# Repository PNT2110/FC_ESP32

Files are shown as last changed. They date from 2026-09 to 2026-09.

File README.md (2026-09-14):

# FC_ESP32 Flight Controller

An ESP32-WROOM-32 based flight controller designed for 1S brushed quadcopters.

## Features
- **MCU**: ESP32-WROOM-32 (8MB Flash)
- **IMU**: MPU-6500 (SPI interface)
- **Motor Drivers**: 4x AO3400 MOSFETs for brushed motors
- **Optical Flow**: UART interface for MTF-01P sensor (JST SH1.0 4-pin)
- **Power**: 1S LiPo input, TPS63001 Buck-Boost for 3.3V, TPS61070 Boost for 5V (USB/Optical flow)
- **USB**: USB-C connector with CH340C USB-to-UART bridge
- **Expansion**: I2C and UART1 breakout headers (2.54mm pitch)
- **Battery Monitor**: Built-in voltage divider for telemetry

## Hardware Setup & Pinout
- **Motors**: J4, J5, J6, J7 pads (AO3400 driven)
- **Optical Flow (J2)**: pin 1 GND, pin 2 +5V_FLOW, pin 3 ESP32 TX (GPIO17 → sensor RX), pin 4 ESP32 RX (GPIO16 ← sensor TX). Verify the actual sensor cable orientation.
- **I2C Expansion (J8)**: VCC, GND, SDA (GPIO4), SCL (GPIO22)
- **UART1 Expansion (J9)**: VCC, GND, TX (GPIO14), RX (GPIO32)
- **Programming**: CH340C DTR/RTS auto-download circuit; no physical Boot/Reset buttons are present in the generated BOM.

## Current status

The subsequent datasheet review found B.Cu tracks inside the ESP32 antenna region,
power-layout concerns and incomplete flight features despite clean ERC/DRC.
See `BAO_CAO_KIEM_TRA_MACH.md` and `validation/datasheet_audit/LOG_KIEM_TRA.md`.
The independent antenna check fails; do not interpret the routing checks below as
proof that the design is ready to operate or manufacture.

PCB routing and final ERC/DRC/parity checks passed on 2026-09-14 (KiCad 10.0.6):
zero violations and zero unconnected items. Motor solder pads moved 1.5 mm inward;
J2 faces outward. See `validation/FINAL_REVIEW.md` and `validation/final_3d.png`.
Not released for manufacturing or flight. Motor pitch is
66.8 mm, prop diameter 40 mm, board thickness 0.8 mm. Components are on the front;
copper routing uses both layers. Firmware motor actuation is disabled by default;
see `firmware/README.md`.

## Reproducible hardware workflow

Use system Python with KiCad 10 `pcbnew`, `sexpdata` and Shapely installed.
The generator replaces the working PCB and therefore discards its routing.
Back up a routed board before regenerating.

```sh
/usr/bin/python3 tools/build_fc.py
/usr/bin/python3 tools/prepare_route.py
# Route the new FC_ESP32/FC_ESP32.dsn with Freerouting and save FC_ESP32.ses.
/usr/bin/python3 tools/import_route.py
/usr/bin/python3 tools/finish_copper.py
python3 tools/validate_fc.py
```

`build_fc.py` now includes clearance-preserving placement and updates the BOM and
design coordinates. Session import validates placement before replacing copper.
The legacy `critical_routes.py` and `repair_connections.py` contain assumptions
from the older layout and are not part of this workflow.

On the current machine, prefix system-Python commands with
`PYTHONPATH=/home/pnt/miniconda3/lib/python3.14/site-packages`.
This path is environment-specific. Generation was verified in an isolated copy;
all 72 component placements, orientations, values, footprints and nets matched.

The current SES predates the final repairs: do not import it onto the final PCB.
`validation/final_routed.kicad_pcb` preserves the reviewed routing.
`tools/repair_c3_ground.py` documents the deterministic final copper repair from
`validation/only_c3_ground_remaining.kicad_pcb` to its candidate output.

Open `FC_ESP32/FC_ESP32.kicad_pro` for review. Validation records current ERC,
DRC, netlist parity and source hashes in `FC_ESP32/validation_summary.json` and
returns nonzero on errors. Reports do not replace current/thermal analysis or
bench testing. `gerbers/` contains stale outputs, not an approved release.

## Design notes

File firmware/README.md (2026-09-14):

# Firmware bring-up

Current firmware includes MPU-6500 acquisition, gyro calibration, attitude estimation,
PID/mixing, battery monitoring and an ESP-NOW command/arming/failsafe path.
Motor actuation is disabled by default (`CONFIG_FC_ENABLE_MOTORS`); the default
build keeps PWM outputs at zero. Host tests pass for the sensor driver, protocol,
arming/failsafe and controller fault/output limits. These tests do not establish
stable flight: transmitter integration, sensor axes, motor order, control tuning
and battery behavior still require hardware testing.

Verified build: ESP-IDF 5.4.2, ESP32 target. Uses `driver/i2c_master.h` and `esp_adc/adc_oneshot.h`:

```sh
idf.py set-target esp32
idf.py build
```

Run from this directory after sourcing the ESP-IDF `export.sh`. The current validation SDK is `/tmp/fc-esp-idf` and its tool installation is
`/tmp/fc-idf-tools` (`IDF_TOOLS_PATH`). These temporary paths do not survive cleanup.
Host SPI regression tests (from repository root):

```sh
bash firmware/tests/run.sh
```

They verify SPI byte alignment, signed conversion, sensor range configuration,
identity rejection and transfer failure handling. They do not emulate electrical
hardware or replace an ESP32 build/bench test.

Driver references:
- https://invensense.tdk.com/wp-content/uploads/2015/02/MPU-6500-Register-Map2.pdf
- https://docs.espressif.com/projects/esp-idf/en/latest/esp32/api-reference/peripherals/spi_master.html

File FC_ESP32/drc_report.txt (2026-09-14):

** Drc report for FC_ESP32.kicad_pcb **
** Created on 2026-09-13T22:51:14 **
** Report includes: Errors, Warnings **

** Found 24 DRC violations **
[silk_overlap]: Silkscreen clearance (board setup constraints silk clearance 0.1000 mm; actual 0.0039 mm)
    Rule: board setup constraints silk; warning
    @(110.5600 mm, 109.9850 mm): Segment of J2 on F.Silkscreen
    @(110.5000 mm, 110.0000 mm): PCB text '1S ONLY' on F.Silkscreen
[silk_over_copper]: Silkscreen clipped by solder mask
    Local override; warning
    @(110.5000 mm, 110.0000 mm): PCB text '1S ONLY' on F.Silkscreen
    @(109.7000 mm, 109.1750 mm): Pad MP [<no net>] of J2 on F.Cu
[silk_over_copper]: Silkscreen clipped by solder mask
    Local override; warning
    @(110.5000 mm, 114.0000 mm): PCB text 'BAT+  BAT-' on F.Silkscreen
    @(108.5000 mm, 112.2000 mm): Pad 1 [VBAT] of J3 on F.Cu
[silk_over_copper]: Silkscreen clipped by solder mask
    Local override; warning
    @(110.5000 mm, 114.0000 mm): PCB text 'BAT+  BAT-' on F.Silkscreen
    @(112.5000 mm, 112.2000 mm): Pad 2 [GND] of J3 on F.Cu
[silk_over_copper]: Silkscreen clipped by solder mask
    Local override; warning
    @(110.5000 mm, 114.0000 mm): PCB text 'BAT+  BAT-' on F.Silkscreen
    @(113.1000 mm, 114.5500 mm): Pad 2 [GND] of Q3 on F.Cu
[silk_over_copper]: Silkscreen clipped by solder mask
    Local override; warning
    @(90.0000 mm, 85.2500 mm): Circle of U1 on F.Silkscreen
    @(89.1000 mm, 85.0500 mm): Pad 2 [GND] of Q1 on F.Cu
[text_height]: Text height out of range (board setup constraints silk text height min height 0.8000 mm; actual 0.6500 mm)
    Rule: board setup constraints silk text height; warning
    @(100.0000 mm, 117.0000 mm): PCB text 'USB' on F.Silkscreen
[text_height]: Text height out of range (board setup constraints silk text height min height 0.8000 mm; actual 0.6500 mm)
    Rule: board setup constraints silk text height; warning
    @(110.5000 mm, 110.0000 mm): PCB text '1S ONLY' on F.Silkscreen
[text_height]: Text height out of range (board setup constraints silk text height min height 0.8000 mm; actual 0.6500 mm)
    Rule: board setup constraints silk text height; warning
    @(110.5000 mm, 114.0000 mm): PCB text 'BAT+  BAT-' on F.Silkscreen
[via_dangling]: Via is not connected or connected on only one layer
    Local override; warning
    @(86.5514 mm, 87.3786 mm): Via [GATE1] on F.Cu - B.Cu
[via_dangling]: Via is not connected or connected on only one layer
    Local override; warning
    @(110.3922 mm, 92.1230 mm): Via [PWM2] on F.Cu - B.Cu
[track_dangling]: Track has unconnected end
    Local override; warning
    @(99.6000 mm, 109.9000 mm): Track [SPI_MISO] on B.Cu, length 0.5160 mm
[track_dangling]: Track has unconnected end
    Local override; warning
    @(100.4000 mm, 109.9359 mm): Track [REGOUT] on F.Cu, length 0.5859 mm
[track_dangling]: Track has unconnected end
    Local override; warning
    @(101.9708 mm, 109.9000 mm): Track [IMU_INT] on B.Cu, length 0.6708 mm
[track_dangling]: Track has unconnected end
    Local override; warning
    @(100.4011 mm, 104.1989 mm): Track [IMU_CS] on F.Cu, length 0.2844 mm
[track_dangling]: Track has unconnected end
    Local override; warning
    @(100.2000 mm, 104.4000 mm): Track [IMU_CS] on B.Cu, length 0.9881 mm
[track_dangling]: Track has unconnected end
    Local override; warning
    @(98.3500 mm, 104.4000 mm): Track [SPI_MOSI] on B.Cu, length 2.5460 mm
[via_dangling]: Via is not connected or connected on only one layer
    Local override; warning
    @(95.9221 mm, 89.0085 mm): Via [+5V_FLOW] on F.Cu - B.Cu
[via_dangling]: Via is not connected or connected on only one layer
    Local override; warning
    @(112.0000 mm, 106.5347 mm): Via [+5V_FLOW] on F.Cu - B.Cu
[via_dangling]: Via is not connected or connected on only one layer
    Local override; warning
    @(111.5559 mm, 97.6595 mm): Via [EN] on F.Cu - B.Cu
[via_dangling]: Via is not connected or connected on only one layer
    Local override; warning
    @(116.8767 mm, 115.3522 mm): Via [GATE3] on F.Cu - B.Cu
[via_dangling]: Via is not connected or connected on only one layer
    Local override; warning
    @(109.3222 mm, 115.4896 mm): Via [M3_NEG] on F.Cu - B.Cu
[via_dangling]: Via is not connected or connected on only one layer
    Local override; warning
    @(95.0887 mm, 110.4342 mm): Via [VSYS] on F.Cu - B.Cu
[via_dangling]: Via is not connected or connected on only one layer
    Local override; warning
    @(104.1904 mm, 101.2292 mm): Via [PWM3] on F.Cu - B.Cu

** Found 16 unconnected pads **
[unconnected_items]: Missing connection between items
    Local override; error
    @(110.3922 mm, 92.1230 mm): Track [PWM2] on F.Cu, length 0.5748 mm
    @(91.5000 mm, 97.9400 mm): Pad 11 [PWM2] of U1 on F.Cu
[unconnected_items]: Missing connection between items
    Local override; error
    @(99.4000 mm, 108.5450 mm): Pad 8 [+3V3_IMU] of U2 on F.Cu
    @(98.8000 mm, 109.3500 mm): Track [+3V3_IMU] on B.Cu, length 1.6539 mm
[unconnected_items]: Missing connection between items
    Local override; error
    @(100.2530 mm, 108.7310 mm): Track [SPI_MISO] on B.Cu, length 2.3442 mm
    @(99.8000 mm, 108.5450 mm): Pad 9 [SPI_MISO] of U2 on F.Cu
[unconnected_items]: Missing connection between items
    Local override; error
    @(100.4000 mm, 109.9359 mm): Track [REGOUT] on F.Cu, length 0.5859 mm
    @(100.2000 mm, 108.5450 mm): Pad 10 [REGOUT] of U2 on F.Cu
[unconnected_items]: Missing connection between items
    Local override; error
    @(101.0000 mm, 108.5450 mm): Pad 12 [IMU_INT] of U2 on F.Cu
    @(101.9708 mm, 109.9000 mm): Track [IMU_INT] on B.Cu, length 0.6708 mm
[unconnected_items]: Missing connection between items
    Local override; error
    @(100.4011 mm, 104.1989 mm): Track [IMU_CS] on F.Cu, length 0.2844 mm
    @(100.2000 mm, 104.4000 mm): Track [IMU_CS] on B.Cu, length 0.9881 mm
[unconnected_items]: Missing connection between items
    Local override; error
    @(100.2000 mm, 104.4000 mm): Track [IMU_CS] on B.Cu, length 0.9881 mm
    @(99.8000 mm, 105.4550 mm): Pad 22 [IMU_CS] of U2 on F.Cu
[unconnected_items]: Missing connection between items
    Local override; error
    @(99.4000 mm, 105.4550 mm): Pad 23 [SPI_SCK] of U2 on F.Cu
    @(108.5000 mm, 95.4000 mm): Pad 30 [SPI_SCK] of U1 on F.Cu
[unconnected_items]: Missing connection between items
    Local override; error
    @(98.3500 mm, 104.4000 mm): Track [SPI_MOSI] on B.Cu, length 2.5460 mm
    @(99.0000 mm, 105.4550 mm): Pad 24 [SPI_MOSI] of U2 on F.Cu
[unconnected_items]: Missing connection between items
    Local override; error
    @(110.6000 mm, 98.0000 mm): Pad 3 [EN] of Q5 on B.Cu
    @(90.2583 mm, 91.9671 mm): Track [EN] on F.Cu, length 1.0851 mm
[unconnected_items]: Missing connection between items
    Local override; error
    @(102.7500 mm, 97.6350 mm): Pad 5 [USB_DP] of U3 on B.Cu
    @(100.1402 mm, 111.3527 mm): Track [USB_DP] on F.Cu, length 0.2183 mm
[unconnected_items]: Missing connection between items
    Local override; error
    @(108.0000 mm, 109.9100 mm): Pad 1 [PWM3] of R19 on F.Cu
    @(97.2374 mm, 101.2292 mm): Track [PWM3] on F.Cu, length 6.9530 mm
[unconnected_items]: Missing connection between items
    Local override; error
    @(87.5000 mm, 89.0000 mm): Pad 2 [BOOST_SW] of L2 on B.Cu
    @(90.8625 mm, 91.4500 mm): Pad 1 [BOOST_SW] of U6 on B.Cu
[unconnected_items]: Missing connection between items
    Local override; error
    @(97.2500 mm, 96.3650 mm): Pad 13 [DTR] of U3 on B.Cu
    @(108.4000 mm, 98.5100 mm): Track [DTR] on B.Cu, length 0.0806 mm
[unconnected_items]: Missing connection between items
    Local override; error
    @(109.4000 mm, 91.0000 mm): Pad 4 [BUCK_L1] of U5 on B.Cu
    @(112.7000 mm, 92.1000 mm): Pad 1 [BUCK_L1] of L1 on B.Cu
[unconnected_items]: Missing connection between items
    Local override; error
    @(109.4000 mm, 90.0000 mm): Pad 2 [BUCK_L2] of U5 on B.Cu
    @(112.7000 mm, 88.9000 mm): Pad 2 [BUCK_L2] of L1 on B.Cu

** Found 0 Footprint errors **

** Ignored checks **
    - Footprint has no courtyard defined
    - Track endpoint not centered on via
    - Tuning profile track geometries
    - Footprint doesn't match symbol's footprint filters
    - Footprint component type doesn't match footprint pads

** End of Report **

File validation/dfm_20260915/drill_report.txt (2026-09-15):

Drill report for FC_ESP32.kicad_pcb
Created on 2026-09-15T04:53:47

Copper Layer Stackup:
    =============================================================
    L1 :  F.Cu                      front
    L2 :  B.Cu                      back

Drill file 'FC_ESP32-PTH.drl' contains
    plated through holes:
    =============================================================
    T1  0.300mm  0.0118"  (163 holes))
    T2  0.600mm  0.0236"  (4 holes)  (with 4 slots)
    T3  1.000mm  0.0394"  (8 holes))

    Total plated holes count 175

Drill file 'FC_ESP32-NPTH.drl' contains
    unplated through holes:
    =============================================================
    T1  0.650mm  0.0256"  (2 holes))
    T2  8.600mm  0.3386"  (4 holes))

    Total unplated holes count 6

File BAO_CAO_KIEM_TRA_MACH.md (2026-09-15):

> Cập nhật 15/09/2026: đã sửa đường VBAT/PWM1 xâm lấn antenna; kiểm tra độc lập cả hai lớp không còn track/via/pad/zone trong vùng antenna. ERC/DRC và kiểm tra đồng nhất schematic/PCB sạch. Chi tiết mới nhất: [log sửa antenna](validation/antenna_fix/BAO_CAO.md). Các nhận xét antenna chưa đạt ở nội dung cũ bên dưới là kết quả trước đợt sửa này.

# Báo cáo đối chiếu datasheet, sơ đồ, PCB, 3D và firmware FC_ESP32

Ngày kiểm tra: 14/09/2026. Công cụ: KiCad 10.0.6, Python/pcbnew, kiểm tra mã C trên host với AddressSanitizer và UndefinedBehaviorSanitizer.

## 1. Kết luận cần đọc trước

**Chưa thể kết luận mạch chắc chắn chạy, và chưa nên đặt sản xuất để bay ngay.** Sơ đồ chân tín hiệu/nguồn đã kiểm tra khớp; ERC/DRC/parity vẫn sạch. Nhưng rà soát theo datasheet đã phát hiện vấn đề anten, layout nguồn và cấu hình/tính năng firmware mà các kiểm tra đó không chứng minh được.

Đặc biệt, **VBAT và PWM1 đang chạy ở B.Cu trong vùng anten ESP32**. Rule area hiện tại chỉ cấm track F.Cu; rule trên hai lớp cấm đổ đồng nhưng cho phép track. Vì vậy kết quả DRC bằng 0 là đúng với bộ rule hiện hành, nhưng không có nghĩa layout đáp ứng yêu cầu anten. Kết luận hoàn tất ở báo cáo trước chỉ có giá trị về kết nối theo rule, không phải xác nhận đủ điều kiện hoạt động.

Trong lượt này chỉ bổ sung công cụ kiểm tra, log và báo cáo; chưa sửa routing hay đổi cấu hình firmware để tránh che mất trạng thái đang được đánh giá.

## 2. Đã kiểm tra những gì, bằng chứng ở đâu

| Hạng mục | Kết quả | Bằng chứng |
|---|---|---|
| Schematic ERC | 0 vi phạm | `validation/datasheet_audit/erc_drc.log` |
| PCB DRC, refill zones | 0 vi phạm theo rule hiện tại | Cùng log; `FC_ESP32/drc_current.json` |
| Kết nối thiếu, schematic parity | Đều 0 | `FC_ESP32/validation_summary.json` |
| Đối chiếu pin độc lập | 135 pad instances được so với mapping datasheet/yêu cầu, không sai net | `validation/datasheet_audit/audit.json` |
| Toàn bộ pad | 279 pad instances ghi lại số chân, tên chân schematic, net schematic/PCB, tọa độ, góc, mặt | `validation/datasheet_audit/pin_audit.csv` |
| Pin không dùng/reserved/flash | Không thấy bị nối vào net chức năng ngoài ý muốn trong các nhóm đã kiểm tra | `tools/review_design.py` |
| GPIO firmware | Các macro giao tiếp/motor khớp yêu cầu và PCB | `validation/datasheet_audit/pin_check.log` |
| Motor pitch, pad dịch, J2, độ dày, netclass | Audit đạt | `validation/datasheet_audit/invariants.json` |
| Anten kiểm tra độc lập | **Không đạt**: 23 đoạn track giao vùng anten; tổng diện tích hợp giao khoảng 2.823 mm²; VBAT/PWM1 ở B.Cu | `validation/datasheet_audit/antenna_audit.json` |
| Firmware host tests | Cả 3 nhóm đạt | `validation/datasheet_audit/firmware_tests.log` |
| ESP-IDF build toàn bộ hiện tại | Chưa chạy trong lượt này; không tìm thấy SDK/toolchain ở các vị trí đã dùng trước | Không coi host tests là build ESP32 |
| 3D mặt trên/mặt dưới | Đã render mới và xem trực tiếp | `validation/datasheet_audit/top_3d.png`, `bottom_3d.png` |
| Đo trên PCB thật, dòng/dao động/nhiệt, bay | Chưa thực hiện | Chưa có phần cứng/kết quả đo |

SHA-256 của schematic, PCB, project, firmware và datasheet local được lưu trong `validation/datasheet_audit/audit.json`. Log kiểm tra không được hiểu là thử nghiệm vật lý.

## 3. Các điểm cần xử lý theo mức ưu tiên

| ID | Mức | Phát hiện và ảnh hưởng | Việc cần làm |
|---|---|---|---|
| RF-01 | Cao | VBAT/PWM1 chạy dưới anten trong hình chữ nhật x=91…109, y=77.75…84.05 mm. Có thể làm giảm tầm liên lạc, tăng nhiễu, mất gói ESP-NOW | Sửa rule cấm track/via/pour trên cả hai lớp tại vùng anten, đi lại hai net, chạy DRC và đo link khi motor hoạt động |
| PWR-01 | Cao | BOOST_FB dài tổng 28.272 mm, U6–C17 cách tâm 7.653 mm; feedback trở lớn 1.8 MΩ/200 kΩ dễ nhạy nhiễu. Đường switch boost dài 11.795 mm | Bố trí lại cụm U6/L2/C17/R12/R13 thành cụm ngắn, có tụ input sát U6; đo ổn định khởi động, ripple và tải bước |
| CFG-01 | Cao trước nạp | BOM ghi ESP32-WROOM-32 (8MB), `sdkconfig.defaults` ép 8 MB. Datasheet ESP32-WROOM-32 tiêu chuẩn ghi 4 MB | Xác định đúng mã module/flash thực tế, kiểm tra flash ID, đồng bộ BOM và sdkconfig. Không tự coi tên thư viện “8MB” là bằng chứng |
| PWR-02 | Cao trước chạy motor | Chưa có mã/datasheet motor 8520 cụ thể, dòng chạy/kẹt và dữ liệu lực đẩy với Gemfan 1635 ba lá. Chưa chứng minh đường nguồn/MOSFET/diode đủ tải | Đo dòng bằng nguồn giới hạn dòng, xác nhận điện áp motor, tính lại đường đồng/diode/nhiệt theo tải thật |
| BOM-01 | Cao trước đặt hàng | L2 chỉ ghi “4.7uH >=1A shielded”, footprint 4×4, chưa có mã. L1 cũng cần xác nhận mã đầy đủ, footprint và đặc tính đúng bản mua | Chốt mã linh kiện, Isat/Irms/DCR/dung sai, điện dung hiệu dụng các MLCC ở điện áp làm việc |
| ASM-01 | Cần xác minh trước lắp | U2 có pad 25 GND trong footprint/library, trong bảng chân datasheet local chỉ định nghĩa 24 chân và không quy định pad 25 là chân tín hiệu GND | Lấy hướng dẫn assembly/land pattern đúng MPU-6500 để xác nhận nối/solder exposed pad; không suy từ hình 3D QFN chung |
| FW-01 | Chưa hoàn thiện chức năng bay | Mặc định motor bị khóa; peer/key ESP-NOW trống; chưa có firmware tay phát trong repo; chưa xử lý optical flow | Hoàn thành tay phát, cấu hình peer/key/channel, parser cảm biến, kiểm tra failsafe và cơ chế điều khiển trước khi mở motor |
| FW-02 | Cao trước bay | PID là hệ số tạm, chưa chứng minh trục IMU/dấu mixer/chiều motor; lỗi IMU hoặc pin dưới 3.5 V làm dừng motor ngay | Kiểm chứng dấu phản hồi, ngưỡng pin dưới tải, hành vi lỗi; cơ chế ngắt này không phải hạ cánh an toàn |
| PCB-01 | Cần đánh giá nguồn | BUCK_L1 có 7.601 mm, BUCK_L2 có 10.296 mm đồng; có đoạn thoát 0.25 mm dù netclass MotorPower 0.8 mm. VSYS có đoạn 0.2402/0.3 mm | Rà lại từng đoạn nguồn xung theo dòng đỉnh; không coi tên netclass là chiều rộng thật của mọi đoạn |
| USB-01 | Cần thử giao tiếp/ESD | USB_DP/DM có tổng 36.581/33.442 mm track, U4 cách J1 khoảng 8.112 mm theo tâm | Xem đường hồi và nhánh ESD, tối ưu vị trí U4 gần cổng, thử nhận USB cả hai chiều cắm; đây không phải kết quả đo impedance/ESD |

TI yêu cầu đường dòng xung ngắn/rộng, tụ và cuộn cảm sát IC, feedback sát control ground. Các chiều dài trên là tổng chiều dài segment mỗi net, không phải phép đo loop inductance hay trực tiếp delay; nhận định rủi ro dựa vào cả vị trí và routing. Nguồn: datasheet TPS6300x §10.1 và TPS6107x §13.1 trong `data_sheet/`.

Về anten, [Espressif hướng dẫn đặt anten ra ngoài board hoặc tạo khoảng trống thích hợp, rồi kiểm tra tầm liên lạc trên sản phẩm hoàn chỉnh](https://docs.espressif.com/projects/esp-hardware-design-guidelines/en/latest/esp32/pcb-layout-design.html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). Lỗi RF-01 được đo trực tiếp từ đồng PCB, không suy đoán từ màu ảnh 3D.

Về flash, [datasheet chính thức ESP32-WROOM-32](https://documentation.espressif.com/esp32-wroom-32_datasheet_en.html) mô tả module tiêu chuẩn 4 MB. Có thể phần cứng mua thực tế là biến thể khác; phải xác nhận thay vì kết luận chắc chắn đã mua sai.

## 4. Sơ đồ khối và nguyên lý mạch

```mermaid
flowchart LR
  BAT["Pin 1S / J3"] --> VBAT["VBAT"]
  VBAT --> MOT["J4–J7 / motor 8520"]
  MOT --> FET["Q1–Q4 low-side PWM"]
  FET --> GND["GND"]
  VBAT --> D5["D5 SS16"]
  USB["J1 USB-C 5V"] --> D6["D6 SS16"]
  D5 --> VSYS["VSYS"]
  D6 --> VSYS
  VSYS --> U5["U5 TPS63001 / 3.3V"]
  U5 --> MCU["ESP32 / U1"]
  U5 --> CH["CH340C / U3"]
  U5 --> IMU["MPU6500 / U2 qua R5"]
  U5 --> U6["U6 TPS61070 / 5V_FLOW"]
  U6 --> FLOW["J2 / MTF-01P"]
  USB <-->|"D+/D- qua bảo vệ U4"| CH
  CH <-->|"UART0 / auto-download"| MCU
  MCU <-->|"SPI"| IMU
  MCU <-->|"UART2"| FLOW
  MCU -->|"GPIO25/26/27/33"| FET
  VBAT --> ADC["R3/R4/C4 / GPIO35"]
  ADC --> MCU
  TX["Tay phát ESP-NOW riêng"] -.-> MCU
```

### Nguồn pin, USB và 3.3 V

J3 pin 1 là VBAT, pin 2 là GND. VBAT cấp motor trực tiếp và đi qua D5 tới VSYS. USB VBUS đi qua D6 tới VSYS. D5/D6 tạo OR nguồn bằng Schottky: cathode pin 1 cùng ở VSYS, anode pin 2 ở từng nguồn vào. Khi có USB, 5 V thường chiếm ưu thế cấp logic. Đây **không phải mạch sạc pin**, không cân bằng pin, không bảo vệ đảo cực toàn bộ mạch. Motor nối trực tiếp VBAT nên D5 không bảo vệ nhánh motor khi đấu ngược pin. Không đưa nguồn 5 V vào J3.

U5 TPS63001 tạo 3.3 V từ VSYS. Pin 1 VOUT và pin 10 FB nối +3V3 đúng yêu cầu bản fixed 3.3 V; L1 nối pin 4–2. Pin 5 VIN, 6 EN, 7 PS/SYNC nối VSYS; PS/SYNC mức cao tắt power-save. Pin 8 VINA được lọc qua R11=100 Ω, C15=100 nF; pin 3 PGND, 9 GND, pad 11 về GND. C12/C13 là tụ đầu vào/ra. Dải input khuyến nghị của IC là 1.8–5.5 V, nhưng cần trừ sụt áp D5 và kiểm tra tải bước/độ bão hòa cuộn cảm. Datasheet TPS6300x, bảng Pin Functions và phần thiết kế ứng dụng.

### Nguồn 5 V cảm biến

U6 TPS61070 lấy đầu vào từ **+3V3**, không trực tiếp từ pin 1S. Pin 6 VBAT và pin 3 EN cùng +3V3; L2 từ +3V3 đến pin 1 SW; pin 2 GND; pin 5 VOUT là +5V_FLOW. R12 từ VOUT đến FB, R13 từ FB xuống GND:

`Vout ≈ 0.5 × (1 + 1.8M / 200k) = 5.0 V`.

Nếu chỉ xét 1% điện trở và VFB=0.495…0.505 V từ datasheet, khoảng tĩnh cực trị xấp xỉ 4.862…5.142 V; không bao gồm ripple, tải bước hay layout. C17 lọc đầu ra; C18 nằm ở nhánh cảm biến.

[MTF-01P dùng 5 V, dòng trung bình 100 mA, UART LVTTL 3.3 V/115200](https://micoair.cn/zh/docs/sensors/sensors/mtf-01p-sensors). Về mức logic có thể nối UART trực tiếp với ESP32. Tải cảm biến 0.5 W, giả thiết boost hiệu suất 85% thì lấy khoảng 178 mA từ rail 3.3 V, chưa cộng ESP32/CH340/IMU và dòng đỉnh. TPS61070 có giới hạn dòng switch, không được diễn giải là “cấp 600 mA ở 5 V”. Chưa có bằng chứng đủ tải đồng thời khi Wi-Fi phát và motor gây nhiễu.

Đường +5V_FLOW có 8.448 mm rộng 0.18 mm, còn lại 0.4 mm. Phép tính đồng 35 µm trong `validation/flow_power_review.json` cho tổng điện trở segment khoảng 0.114 Ω và sụt khoảng 11.4 mV ở 100 mA. Đây chỉ là đánh giá tổn hao DC của đường đồng, không giải quyết rủi ro layout boost nêu trên.

### MCU, reset, nạp chương trình

ESP32 pin 2 dùng 3.3 V; pin 1/15/38 và exposed ground pad 39 về GND. R1=10 kΩ kéo EN lên, C3=1 µF về GND tạo hằng số RC danh định 10 ms. R2=10 kΩ kéo GPIO0/BOOT lên. GPIO6–11 dùng cho flash được để không nối ra ứng dụng; GPIO34/35 là input-only, đang dùng đúng cho INT và ADC.

CH340C được cấp 3.3 V ở VCC pin 16 và V3 pin 4, đúng chế độ 3.3 V trong datasheet; C9=100 nF decouple. TXD pin 2 tới RX0 ESP32; RXD pin 3 nhận TX0 ESP32. CH340C có oscillator nội, không cần thạch anh ngoài. Pin 15 R232 nối GND; pin 7 NC và các modem input không dùng được để trống.

Q5/Q6 MMBT3904 có pin 1 base, 2 emitter, 3 collector. Q5 kéo EN khi DTR cao/RTS thấp; Q6 kéo BOOT khi RTS cao/DTR thấp. Hai mức DTR/RTS bằng nhau không bật transistor. Tên DTR#/RTS# active-low ở driver cần phân biệt với mức điện áp trên chân. Mạch này cho phép auto-download nhưng vẫn phải thử bằng esptool/driver thật. Không có nút BOOT/RESET vật lý trong BOM hiện tại.

USB-C có CC1/CC2 mỗi đường điện trở 5.1 kΩ về GND; D+ A6/B6 nối nhau, D− A7/B7 nối nhau. U4 USBLC6-2SC6 nối 1/6 với D−, 3/4 với D+, 2 GND và 5 VBUS, khớp [sơ đồ chân ST](https://www.st.com/resource/en/datasheet/usblc6-2.pdf). SBU không dùng. USB cung cấp giao tiếp USB–UART, không phải USB native của MCU, cũng không phải bộ sạc LiPo.

### MPU-6500

R5=10 Ω và các tụ C5/C6/C8 lọc rail +3V3_IMU. Pin 8 VDDIO và 13 VDD dùng rail này; pin 18 GND. Pin 10 REGOUT chỉ nối C7=100 nF về GND, không dùng làm nguồn ngoài. FSYNC pin 11 và reserved pin 20 nối GND; pin 19 reserved để trống. CS pin 22 được R6 kéo lên; SCLK pin 23, SDI pin 24, SDO pin 9, INT pin 12. Các chân NC và AUX không dùng không bị nối ra mạch chức năng. Đối chiếu datasheet MPU-6500 bảng 10, trang 17 và bảng linh kiện ứng dụng trang 19.

**Riêng exposed pad 25:** thư viện thêm pad này và nối GND; pin table local không đủ chứng cứ về yêu cầu hàn/nối pad đáy. Vấn đề này còn mở, không được tính là đã đạt hoàn toàn theo datasheet.

### Motor và phép đo pin

Mỗi motor nhận cực + từ VBAT, cực − đi vào drain pin 3 AO3400. Source pin 2 về GND; gate pin 1 nhận PWM qua 100 Ω, có 100 kΩ kéo xuống để tắt khi MCU chưa điều khiển. D1–D4 SS16 có cathode về VBAT, anode về drain: hướng diode hồi tiếp đúng. Tụ 100 nF trên mỗi nhánh giúp lọc nhiễu; hiệu quả còn phụ thuộc chiều dài dây và nguồn nhiễu tại chổi than.

AO3400 có RDS(on) tối đa 52 mΩ được đặc tả ở VGS=2.5 V, nên có cơ sở dùng gate logic 3.3 V. Không được lấy con số dòng 5.8 A ở VGS=10 V làm mức chịu tải đảm bảo trên cánh PCB nhỏ. SS16 được định mức dòng trung bình 1 A theo điều kiện datasheet; cần tính dòng hồi tiếp theo dạng sóng PWM, không chỉ dòng trung bình nguồn. Ví dụ tổn hao dẫn MOSFET xấp xỉ `I² × RDS(on) × duty`; ở 2 A, 52 mΩ và duty 1 đã là 0.208 W trước khi tính tăng điện trở theo nhiệt. Đây là ví dụ tính, không phải dòng motor đã đo.

R3/R4=100 kΩ chia VBAT đôi vào GPIO35/ADC1_CH7. Ở pin 4.35 V, ADC khoảng 2.175 V; dòng cầu chia khoảng 21.75 µA. C4=100 nF và trở Thevenin 50 kΩ tạo hằng số thời gian khoảng 5 ms. Firmware đổi ADC đã hiệu chuẩn ra volt rồi nhân 2. Sai số điện trở/ADC/Vref phải so lại bằng đồng hồ. Nhãn pin 3.8 V là điện áp danh định; điện áp sạc tối đa phải lấy từ chính nhãn/datasheet pack, không tự suy chắc chắn là 4.35 V.

## 5. Bảng chân ESP32 và nối thiết bị ngoài

Quy ước nhìn **mặt linh kiện**, anten ở trên, USB ở dưới. GPIO là số GPIO của ESP32; “pad U1” là số chân module, hai loại số không thay thế nhau.

| Chức năng | GPIO | Pad U1 | Đầu bên kia |
|---|---:|---:|---|
| Motor M1 — trên trái | 25 | 10 | R15 → Q1 gate → J4 |
| Motor M2 — trên phải | 26 | 11 | R17 → Q2 gate → J5 |
| Motor M3 — dưới phải | 27 | 12 | R19 → Q3 gate → J6 |
| Motor M4 — dưới trái | 33 | 9 | R21 → Q4 gate → J7 |
| MPU MISO | 19 | 31 | U2 pin 9 SDO |
| MPU MOSI | 23 | 37 | U2 pin 24 SDI |
| MPU SCLK | 18 | 30 | U2 pin 23 |
| MPU CS | 21 | 33 | U2 pin 22 |
| MPU INT | 34 | 6 | U2 pin 12 |
| Optical-flow TX | 17 | 28 | J2 pin 3 → RX cảm biến |
| Optical-flow RX | 16 | 27 | J2 pin 4 ← TX cảm biến |
| I2C SDA | 4 | 26 | J8 pin 3 |
| I2C SCL | 22 | 36 | J8 pin 4 |
| UART1 TX | 14 | 13 | J9 pin 3 → RX thiết bị |
| UART1 RX | 32 | 8 | J9 pin 4 ← TX thiết bị |
| UART0 RX/nạp | 3 | 34 | U3 pin 2 TXD |
| UART0 TX/log | 1 | 35 | U3 pin 3 RXD |
| Đo pin | 35 | 7 | R3/R4/C4 |
| Boot strap | 0 | 25 | R2 và Q6 |
| Enable/reset | — | 3 | R1/C3/Q5 |

| Connector | Pin 1 | Pin 2 | Pin 3 | Pin 4 |
|---|---|---|---|---|
| J2 MTF-01P | GND | +5V_FLOW | FC TX → sensor RX | FC RX ← sensor TX |
| J3 pin 1S | VBAT + | GND − | — | — |
| J4/J5/J6/J7 motor | VBAT + | Cực − được PWM, **không phải GND cố định** | — | — |
| J8 I2C | +3V3 | GND | SDA | SCL |
| J9 UART1 | +3V3 | GND | TX | RX |

J2 quay 90° ra cạnh phải. Theo tọa độ PCB, pin 1 ở (111.95,108.3), pin 4 ở (111.95,105.3): **pin 1 nằm phía USB hơn pin 4** khi nhìn mặt trên. Không lấy thứ tự trái/phải của đầu cáp đang cầm để suy số chân; phải đo continuity cáp. J3: pad + ở (108.25,112.2), pad − ở (112.25,112.2).

J8/J9 là tín hiệu 3.3 V; không đưa UART TTL 5 V hoặc RS-232 ±V vào GPIO. I2C có pull-up R23/R24=4.7 kΩ lên 3.3 V. ESP-NOW không dùng connector tín hiệu riêng: tay phát là một ESP khác giao tiếp vô tuyến, phải cùng channel và thông tin peer/key phù hợp.

## 6. Firmware hiện tại thực sự làm được gì

| Tính năng | Có trong code | Mức xác nhận |
|---|---|---|
| Khởi tạo SPI MPU-6500, đọc accel/gyro | Có; SPI mode 3, 1 MHz; WHO_AM_I=0x70 | Host test driver đạt; chưa đọc từ PCB thật |
| Cấu hình ±8g, ±2000 dps | Có; hệ số 4096 LSB/g và 16.4 LSB/(°/s) | So với giá trị cấu hình; chưa hiệu chuẩn thực tế |
| Vòng điều khiển danh định 500 Hz | Có; FreeRTOS tick 1 kHz, chu kỳ 2 ms | Chưa đo jitter trên ESP32 khi radio chạy |
| Calibrate gyro | Có, 500 mẫu đứng yên/gần cân bằng | Khoảng 1 giây nếu đạt điều kiện 500 Hz; host test đạt |
| Roll/pitch estimator, PID/mixer 4 motor | Có; filter bổ sung và rate PID; roll/pitch mục tiêu tối đa khoảng ±20°, yaw rate ±120°/s | Hệ số tạm; chưa chứng minh dấu trục, ổn định hoặc bay |
| PWM 4 kênh | Có, **400 Hz, 13 bit** | Mặc định tất cả duty=0; chưa thử tối ưu với motor brushed |
| ESP-NOW receiver và decode lệnh | Có; 24 byte, magic FC01, session/sequence, throttle/sticks/arm | Logic host test đạt; radio thực chưa integration-test |
| Chống packet trùng/cũ và arm throttle=0 | Có | Host test đạt; không thay thế audit bảo mật toàn hệ |
| Mất lệnh ≥250 ms → disarm | Có trong state machine | Hiệu lực cần task còn chạy; chưa thử tay phát thật |
| Đo pin và ngắt ngoài 3.5…4.45 V | Có, ADC mỗi 20 ms | Ngưỡng cố định; không có hạ cánh tự động; cần thử sụt áp motor |
| Optical flow/LiDAR | **Chỉ init UART2 115200, chưa có uart_read/parser** | Chưa đo khoảng cách/tốc độ từ cảm biến, chưa giữ vị trí/độ cao |
| I2C mở rộng | Tạo bus; chưa thêm device driver | Macro 400 kHz chưa được dùng để đặt tốc độ cho một device |
| UART1 mở rộng | Init 115200 8N1 | Chưa có protocol ứng dụng |
| Telemetry về tay phát | Không có đường gửi trong fc_radio.c | Hiện log ra UART0/USB; chưa có telemetry vô tuyến |
| Firmware tay điều khiển ESP-NOW | Không thấy project tay phát trong repo | Cần viết/ghép với protocol hiện tại |
| Sạc pin, GPS, giữ hướng la bàn, return-home | Không có phần cứng/phần mềm hoàn chỉnh tương ứng | Không được quảng cáo là tính năng hiện tại |

Các cấu hình `CONFIG_FC_TX_MAC`, `CONFIG_FC_PMK`, `CONFIG_FC_LMK` mặc định trống nên `fc_radio_init()` trả lỗi cấu hình nếu chưa điền. `CONFIG_FC_ENABLE_MOTORS` mặc định `n`. Vì vậy bản mặc định **không phải nạp lên là điều khiển motor bằng tay ngay**.

Packet ESP-NOW theo little-endian: byte 0–3 `FC01`; 4–7 session; 8–11 sequence; 12–13 throttle 0…1000; 14–15 roll, 16–17 pitch, 18–19 yaw mỗi giá trị −1000…1000; byte 20 arm 0/1; 21–23 bằng 0. Khởi đầu gửi disarm/throttle 0, sau đó arm/throttle 0. Chi tiết mã gốc ở `firmware/PROTOCOL.md` và `fc_command.[ch]`.

Motor mixing trong code giả định thứ tự NW, NE, SE, SW. Chưa có biến đổi trục cảm biến sang body frame được chứng minh cho hướng lắp này; cần thử nghiêng mạch và xem motor phản hồi đúng chiều chống lại chuyển động. Khi mất IMU hoặc pin ngoài khoảng, controller reset và ra duty 0. Không có bộ giám sát đầu ra motor độc lập đã được kiểm thử cho tình huống task treo; host tests không bao phủ treo MCU/driver, radio callback hoặc brownout.

## 7. PCB và 3D so với yêu cầu cơ khí

Tâm motor là (66.6,66.6), (133.4,66.6), (133.4,133.4), (66.6,133.4) mm. Pitch gần nhất 66.8 mm. Với đường kính cánh 40 mm, khoảng cách danh định giữa hai mép đĩa cánh kề nhau là 26.8 mm. PCB dày 0.8 mm. J4–J7 đã dịch 1.5 mm vào tâm, và linh kiện lắp phía trên.

Lỗ motor danh định 8.6 mm so với motor gọi là 8.5 mm chỉ chênh 0.1 mm đường kính; chưa có dung sai thân motor, giữ motor, chiều cao trục/cánh, bản gá pin hoặc dây thật trong assembly. Không kết luận chắc chắn lắp vừa/không rung chỉ từ tên “8520”. Hình 3D hiện tại không có đủ motor/cánh/pin/cáp để chứng minh chống va chạm, trọng tâm hay đủ lực nâng.

Đã xem 3D: J2 mở ra phải, USB ra dưới; chân model SOIC/SOT/QFN chính đặt trên vùng pad tương ứng; mặt dưới không có linh kiện SMD ngoài chân xuyên lỗ header/connector. Tuy nhiên hình 3D không chứng minh thứ tự chân điện, chất lượng mối hàn, exposed pad, hoặc mã linh kiện đúng. L1/L2 dùng model bao 4×4 tham khảo; header cũng cần chốt chiều cao thực. Không phát hiện rõ một model chính bị quay lệch khỏi toàn bộ pad, nhưng chưa thực hiện kiểm tra solid collision bằng STEP assembly hoàn chỉnh.

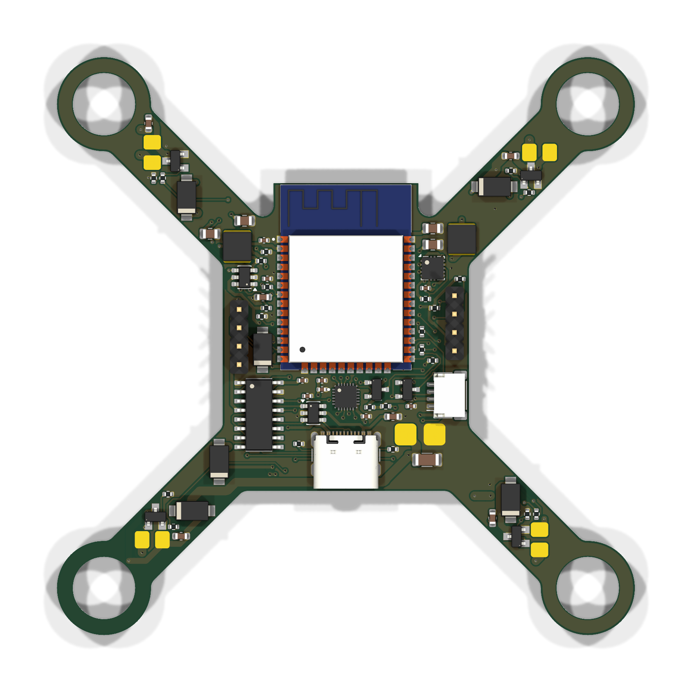
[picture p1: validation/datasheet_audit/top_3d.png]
Mặt trên PCB


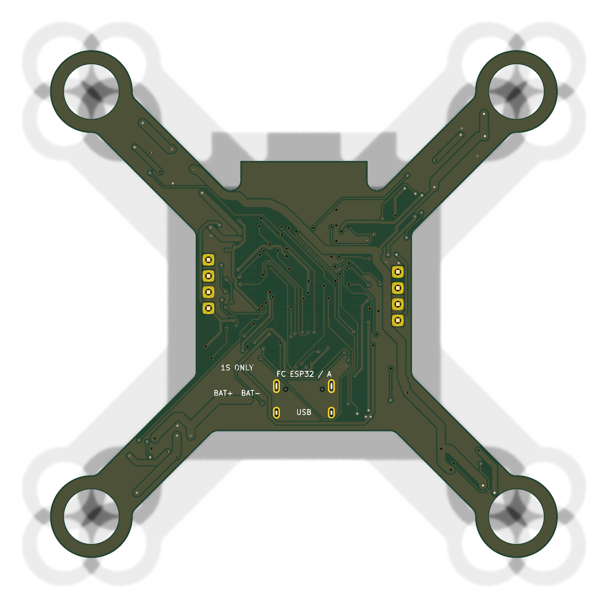
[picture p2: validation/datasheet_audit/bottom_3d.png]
Mặt dưới PCB


## 8. Điều kiện để chuyển từ “thiết kế có cơ sở” sang “đã chạy được”

1. Sửa RF-01, rút ngắn cụm nguồn xung, chốt L1/L2 và MPU exposed pad; tái sinh đúng generator, reroute và chạy lại toàn bộ audit.
2. Xác nhận mã ESP32/flash, motor và điện áp sạc pack; build ESP-IDF đúng target/config, giữ motor disabled cho bring-up.
3. Không gắn cánh; đo continuity và cực nguồn, cấp nguồn giới hạn dòng, đo VSYS/3.3V/5V cả USB-only, pin-only và hai nguồn cùng lúc. Xem overshoot/ripple bằng oscilloscope khi ESP-NOW phát và khi đổi tải.
4. Nạp qua USB, đọc flash ID/boot log; kiểm tra WHO_AM_I 0x70, accel/gyro và trục nghiêng, ADC so với đồng hồ. Xác nhận nguồn IMU không sụt bất thường qua R5.
5. Hoàn thành tay phát, kiểm tra arm/disarm, packet mất/trùng/sai, restart tay phát, khởi động mất link, ngắt dưới tải và thứ tự từng motor khi không có cánh.
6. Chọn protocol MTF-01P và viết parser/kiểm tra timestamp, chất lượng và hướng cảm biến trước khi tuyên bố giữ độ cao/vị trí. Code hiện tại chưa thực hiện bước này.
7. Đo motor một kênh rồi bốn kênh, nhiệt MOSFET/diode/đường đồng, điện áp pin khi tải; kiểm tra đường hồi nhiễu và ESP-NOW khi motor chạy. Dòng kẹt chỉ thử bằng thiết bị/quy trình giới hạn năng lượng phù hợp, không giữ kẹt motor từ LiPo trực tiếp.
8. Xác nhận dấu mixer, chiều quay/cánh, rung, trọng tâm và lực đẩy; tune PID trên gá phù hợp rồi mới đánh giá bay. Ghi số đo và điều kiện vào log; không đánh dấu “pass” cho bước chưa làm.

## 9. Nguồn tra và cách chạy lại

Datasheet local đã chuyển thành text và giữ nguyên PDF gốc: ESP32-WROOM-32 V2.9, MPU-6500 PS-MPU-6500A-01 rev1.3, TPS6300x SLVS520C, TPS6107x SLVS510E, CH340DS1, AO3400 rev8, MMBT3904, SS16 và USB4105. Text ở `validation/datasheet_audit/*.txt`; một số bản pinout dạng hình đã render ra PNG để xem. Tên file ESP32 local chứa “8MB” không làm thay đổi nội dung datasheet tiêu chuẩn.

Nguồn online bổ sung: [ESP32 datasheet](https://documentation.espressif.com/esp32-wroom-32_datasheet_en.html), [hướng dẫn PCB ESP32](https://docs.espressif.com/projects/esp-hardware-design-guidelines/en/latest/esp32/pcb-layout-design.html), [USBLC6-2 ST](https://www.st.com/resource/en/datasheet/usblc6-2.pdf), [MTF-01P MicoAir](https://micoair.cn/zh/docs/sensors/sensors/mtf-01p-sensors), [USB4105 GCT](https://gct.co/files/drawings/usb4105.pdf). Không dùng datasheet linh kiện “gần giống” để xác nhận thay thế footprint.

```bash
kicad-cli sch export netlist FC_ESP32/FC_ESP32.kicad_sch \
  -o validation/datasheet_audit/fresh.net --format kicadxml
PYTHONPATH=/home/pnt/miniconda3/lib/python3.14/site-packages \
  /usr/bin/python3 tools/review_design.py
python3 tools/validate_fc.py
bash firmware/tests/run.sh
```

`review_design.py` hiện trả exit code 1 vì lỗi anten, dù `connectivity_pass=true`. Chi tiết vi phạm có UUID trong `antenna_audit.json`; `automated_checks_pass=false` thể hiện kiểm tra bổ sung chưa đạt. Các issue trong bảng §3 chưa được tự động sửa trong lượt báo cáo này.

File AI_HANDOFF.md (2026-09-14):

# Bàn giao dự án FC_ESP32 cho AI tiếp theo

> Rà soát datasheet mới nhất phát hiện lỗi track VBAT/PWM1 trên B.Cu dưới anten, các rủi ro nguồn và chức năng firmware chưa hoàn thiện. Trạng thái chi tiết có trong `BAO_CAO_KIEM_TRA_MACH.md`; kiểm tra anten độc lập đang FAIL dù DRC=0. Ưu tiên báo cáo này hơn các kết luận cũ bên dưới.

> Cập nhật sau khi người dùng cho phép tiếp tục: PCB chính đã nối đủ và đạt ERC/DRC/parity 0 lỗi trên KiCad 10.0.6. Xem `validation/FINAL_REVIEW.md` để biết trạng thái mới nhất. Nội dung bên dưới là lịch sử bàn giao trước khi sửa xong C3; không dùng các lỗi còn thiếu bên dưới làm trạng thái hiện tại.

Tiếp tục dự án KiCad 10 tại `/home/pnt/FC_ESP32`. Đọc `AGENTS.md` và kiểm tra trạng thái file thực tế trước khi sửa. Không xem dự án là hoàn tất khi còn lỗi kết nối.

Thông tin dưới đây ghi lại trạng thái khi dừng ngày 2026-09-14, không thay thế việc kiểm tra lại PCB hiện tại. Người dùng đã yêu cầu dừng công việc và viết tài liệu bàn giao; chỉ tiếp tục chỉnh sửa khi được yêu cầu.

## Yêu cầu đã chốt

- Flight controller ESP32-WROOM-32 cho quad brushed 1S.
- Motor coreless 8520, cánh Gemfan 40mm 1635 ba lá.
- Pin Tattu Rline 550mAh 1S 95C, danh định 3.8V.
- Điều khiển bằng tay ESP-NOW riêng.
- Giữ khoảng cách motor kề nhau 66.8mm, PCB dày 0.8mm và antenna keepout.
- Linh kiện lắp một mặt trên.
- J2 phải quay đầu cắm ra ngoài phía phải.
- Dịch các pad hàn dây motor vào trong một chút, hoàn thành đi dây, kiểm tra điện và hướng linh kiện trên bản 3D.

## Đã làm

- J4–J7 đã dịch 1.5mm theo hướng tâm; không dịch tâm motor.
- J2 ở `(113.95,106.8)`, góc 90°: pin 1 GND, 2 +5V_FLOW, 3 FLOW_TX, 4 FLOW_RX.
- J8 chuyển đến `(115,96.85)` để nhường đường đi dây.
- Đã sửa một số model 3D và artwork; vẫn phải kiểm tra lại bản render cuối.
- C3 hiện ở khoảng `(88.55,93.25)`, góc 180°.
- EN đã nối đủ sau khi đi lại một phần +5V_FLOW.
- Snapshot gần hoàn thiện: `validation/only_c3_ground_remaining.kicad_pcb`.

## Trạng thái khi dừng

PCB chính đã được khôi phục từ snapshot trên: `FC_ESP32/FC_ESP32.kicad_pcb`.

Kết quả kiểm tra tương ứng gần nhất:

- ERC: 0 lỗi.
- Schematic parity: 0 lỗi.
- Không có lỗi short/clearance.
- Còn 1 vùng GND cô lập quanh chân mass C3.
- Có 3 cảnh báo `via_dangling` trên +5V_FLOW, BOOST_FB và PWM4.

Hãy chạy lại kiểm tra để xác nhận trạng thái thực tế.

## Vấn đề cần giải quyết

Mass C3 bị bao bởi BOOST_FB ở F.Cu; VBAT rộng 1.2mm ở B.Cu chặn vị trí via.

Các thử nghiệm đã thất bại và đã hoàn tác:

- Bóc BOOST_FB, nối mass C3 đường ngắn rồi đi lại BOOST_FB: không tìm được đường.
- Xoay C3 90°/270° trong vùng ±4mm: không có vị trí đạt kiểm tra courtyard với bố trí hiện tại.

Đừng lặp vô hạn những thử nghiệm này. Hãy xem xét điều chỉnh cục bộ đường đồng hoặc bố trí linh kiện lân cận.

Cần lưu ý: đoạn +5V_FLOW mới nối dùng 0.18mm vì thử 0.4mm không đi được. Phải đánh giá lại đường cấp nguồn thực tế, không chỉ nhìn netclass.

## Công cụ và nguồn dữ liệu

- `tools/build_fc.py` là nguồn sinh phần cứng. Thay đổi bố trí/footprint phải cập nhật generator và kiểm tra tái sinh; không chạy generator trực tiếp làm mất bản đã route.
- `tools/route_remaining.py`: router phụ, có `--source-ref C3`, `--ignore-zones`, `--sense-branch`. DRC mới là kết luận.
- `tools/import_route.py` đã bổ sung kiểm tra góc và mặt linh kiện trước khi import.
- `FC_ESP32/FC_ESP32.ses` hiện cũ, C3 vẫn góc 0°: **không import vào PCB hiện tại**.
- `tools/validate_fc.py` chạy ERC/DRC/parity.
- `tools/audit_board.py` kiểm tra pad motor, J2, C3, pin/net và chiều rộng công suất.

Chạy công cụ pcbnew bằng môi trường đã dùng trong phiên trước; kiểm tra lại đường dẫn nếu môi trường thay đổi:

```bash
PYTHONPATH=/home/pnt/miniconda3/lib/python3.14/site-packages /usr/bin/python3 tools/<script>.py
```

## Giới hạn

- Giữ netclass Battery 1.2mm, MotorPower 0.8mm, LogicPower 0.4mm, Default 0.18mm.
- Không thu hẹp đường pin/motor để ép route.
- Nhánh đo VBAT 0.4mm có đánh giá riêng trong `FC_ESP32/adc_branch_review.json`; không mở rộng ngoại lệ này sang đường công suất.
- Không bỏ linh kiện bảo vệ/lọc.
- Một số model cuộn cảm chỉ là hình bao tham khảo; chưa được coi là xác nhận đúng linh kiện.
- Firmware chưa được coi là đã kiểm chứng bay. Giữ cấu hình vô hiệu hóa motor mặc định và kiểm tra riêng nếu tiếp tục phần firmware.

## Điều kiện hoàn tất

1. Nối mass C3 và xử lý via thừa.
2. ERC/DRC không còn lỗi hoặc unconnected; kiểm tra parity và audit.
3. Kiểm tra bản 3D cuối: J2 hướng ra ngoài, hướng/chân model đúng footprint.
4. Đối chiếu BOM, `design.json`, PCB và generator.
5. Lưu bản cuối cùng và báo rõ các giới hạn chưa kiểm chứng.

Gerber cũ có thể stale. Không đặt hàng hoặc tuyên bố đủ điều kiện bay chỉ vì DRC sạch.

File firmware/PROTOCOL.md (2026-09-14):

# ESP-NOW command protocol v1

Use encrypted unicast ESP-NOW on channel 6 (configurable), station interface on
both devices. Configure transmitter MAC without separators, PMK and peer LMK in
`idf.py menuconfig` → FC ESP-NOW receiver. Keys must be 16 bytes represented by
32 hexadecimal digits and match the transmitter. Empty defaults disable radio
initialization; they are not shared production credentials.

Send 50–100 packets/second. Use `fc_command_encode` from `main/fc_command.c` on
the transmitter; never transmit the in-memory C struct. Each packet is 24 bytes:

| Offset | Length | Field |
|---|---|---|
| 0 | 4 | ASCII `FC01` |
| 4 | 4 | Random session ID generated at transmitter boot |
| 8 | 4 | Increasing sequence number, wraps at 2^32 |
| 12 | 2 | Throttle 0–1000 |
| 14 | 2 | Signed roll stick −1000–1000 |
| 16 | 2 | Signed pitch stick −1000–1000 |
| 18 | 2 | Signed yaw stick −1000–1000 |
| 20 | 1 | Arm switch: 0 or 1 |
| 21 | 3 | Reserved, all zero |

Integers are little-endian. Stick axes are normalized inputs, not angles, rates,
or PWM values. Aircraft axis mapping must be defined and bench-checked when the
controller is implemented.

The receiver rejects wrong lengths, magic, reserved bytes, value ranges, source
MAC, broadcast destination, duplicate or backwards sequence numbers. A new
session must first send disarmed with throttle zero. Arming requires a disarmed
zero-throttle packet followed by an armed zero-throttle packet. A high-throttle
arm attempt consumes this permission: switch off and retry at zero throttle.

After 250 ms without a fresh accepted packet the logical gate closes. Continuing
to send arm=1 cannot rearm it: a new disarm/zero-throttle step is required. A new
session also resets the gate. Packet processing runs in the Wi-Fi callback;
control code calls `fc_radio_snapshot` periodically to evaluate link freshness.

The current bring-up task polls at 100 ms. Consequently a future motor control
integration must use its own fast periodic deadline and stop outputs on a false
snapshot; this code does not promise a 250 ms physical motor-stop latency. Motors
are permanently inhibited in the current build.

The MAC filter and sequence checks supplement ESP-NOW, not application-level
cryptographic authentication. Validation so far covers the codec/gate with host
tests and an ESP32 build. Two-device radio, key-mismatch and loss-of-link bench
tests remain required.

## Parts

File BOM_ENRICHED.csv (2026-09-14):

Reference | Value | Footprint | Datasheet | Library | Status
U1 | ESP32-WROOM-32 (8MB) | FC_Local:ESP32 | https://documentation.espressif.com/esp32-wroom-32_datasheet_en.html | Library/ESP32-WROOM-32_8MB_/ESP32-WROOM-32_8MB_.kicad_sym | Verify purchased flash variant; local PDF available
U2 | MPU-6500 | FC_Local:MPU6500 | https://invensense.tdk.com/wp-content/uploads/2015/02/MPU-6500-Register-Map2.pdf | Library/MPU-6500/MPU-6500.kicad_sym | Datasheet and exposed-pad assembly still require confirmation
U3 | CH340C | FC_Local:CH340C | https://www.wch-ic.com/downloads/CH340DS1_PDF.html | Library/CH340C/CH340C.kicad_sym | Confirmed against local datasheet
U4 | USBLC6-2SC6 | FC_Local:SOT-23-6 | https://www.st.com/resource/en/datasheet/usblc6-2.pdf | /usr/share/kicad/symbols/Power_Protection.kicad_sym | Confirm exact SOT-23-6 pin-compatible part
U5 | TPS63001DRCR | FC_Local:Texas_DRC0010J | https://www.ti.com/lit/ds/symlink/tps63001.pdf | /usr/share/kicad/symbols/Regulator_Switching.kicad_sym | Confirmed package/pin mapping; verify sourcing
U6 | TPS61070DDCR | FC_Local:SOT-23-6 | https://www.ti.com/lit/ds/symlink/tps61070.pdf | Datasheet-derived local symbol | Confirm exact DDCR footprint and source
L1 | 2.2uH VLF4012-2R2M1R5 | FC_Local:L_VLF4012 | https://product.tdk.com/system/files/dam/doc/product/inductor/inductor/smd/catalog/inductor_commercial_power_mld_vlf-e.pdf | Library/FC_Local/FC_Local.pretty/L_VLF4012.kicad_mod | Confirm exact manufacturer part / Isat / Irms / DCR
L2 | 4.7uH >=1A shielded | FC_Local:L_4x4 | https://www.coilcraft.com/getmedia/3b3e9a0d-85f6-4eb1-8e9d-2a7d6f6ad6a2/lps4012.pdf | Library/FC_Local/FC_Local.pretty/L_4x4.kicad_mod | Missing exact orderable part; do not order until selected
D1-D6 | SS16 | FC_Local:SS16 | https://www.diodes.com/assets/Datasheets/SS12-SS16.pdf | Library/SS16/SS16.kicad_sym | Confirmed electrical class; verify vendor suffix
Q1-Q4 | AO3400 | FC_Local:AO3400 | https://www.aosmd.com/sites/default/files/res/datasheets/AO3400.pdf | Library/AO3400/AO3400.kicad_sym | Confirmed against local datasheet
Q5-Q6 | MMBT3904 | FC_Local:MMBT3904 | https://www.diodes.com/assets/Datasheets/MMBT3904.pdf | Library/MMBT3904/MMBT3904.kicad_sym | Confirm vendor pinout before assembly
J1 | USB4105-GF-A | FC_Local:USB_C | https://gct.co/files/drawings/usb4105.pdf | Library/2345986-1/2345986-1.kicad_sym | Check exact GCT/TE ordering discrepancy in source files
J2 | MTF-01P SH1.0 | FC_Local:JST_SH_SM04B-SRSS-TB_1x04-1MP_P1.00mm_Horizontal | https://www.jst-mfg.com/product/pdf/eng/eSH.pdf | Library/FC_Local/FC_Local.pretty/JST_SH_SM04B-SRSS-TB_1x04-1MP_P1.00mm_Horizontal.kicad_mod | Confirm cable orientation and sensor mating part
J3 | BAT 1S | FC_Local:Battery_Wire_Pads |  | Library/FC_Local/FC_Local.pretty/Battery_Wire_Pads.kicad_mod | Custom wire pads; no standalone component datasheet
J4-J7 | M1-M4 + / - | FC_Local:Motor_Wire_Pads |  | Library/FC_Local/FC_Local.pretty/Motor_Wire_Pads.kicad_mod | Custom wire pads; no standalone component datasheet
J8-J9 | I2C/UART1 | FC_Local:Header_1x04_P2.54mm |  | Library/FC_Local/FC_Local.pretty/Header_1x04_P2.54mm.kicad_mod | Generic header; select mating/header manufacturer
C1,C17 | 22uF 10V X5R | FC_Local:C_0805_2012Metric | https://product.tdk.com/system/files/dam/doc/product/capacitor/ceramic/mlcc/catalog/mlcc_commercial_general_en.pdf | /usr/share/kicad/symbols/Device.kicad_sym | Value/voltage class only; exact MLCC part missing
C2,C4-C5,C7,C9,C15,C18 | 100nF | FC_Local:C_0402_1005Metric | https://product.tdk.com/system/files/dam/doc/product/capacitor/ceramic/mlcc/catalog/mlcc_commercial_general_en.pdf | /usr/share/kicad/symbols/Device.kicad_sym | Value only; exact MLCC part missing
C3,C8 | 1uF | FC_Local:C_0603_1608Metric | https://product.tdk.com/system/files/dam/doc/product/capacitor/ceramic/mlcc/catalog/mlcc_commercial_general_en.pdf | /usr/share/kicad/symbols/Device.kicad_sym | Value only; exact MLCC part missing
C6 | 10nF | FC_Local:C_0402_1005Metric | https://product.tdk.com/system/files/dam/doc/product/capacitor/ceramic/mlcc/catalog/mlcc_commercial_general_en.pdf | /usr/share/kicad/symbols/Device.kicad_sym | Value only; exact MLCC part missing
C11 | 1uF 10V | FC_Local:C_0603_1608Metric | https://product.tdk.com/system/files/dam/doc/product/capacitor/ceramic/mlcc/catalog/mlcc_commercial_general_en.pdf | /usr/share/kicad/symbols/Device.kicad_sym | Value only; exact MLCC part missing
C12-C13 | 10uF 10V X5R | FC_Local:C_0805_2012Metric | https://product.tdk.com/system/files/dam/doc/product/capacitor/ceramic/mlcc/catalog/mlcc_commercial_general_en.pdf | /usr/share/kicad/symbols/Device.kicad_sym | Value/voltage class only; exact MLCC part missing
C19 | 47uF 10V X5R | FC_Local:C_1206_3216Metric | https://product.tdk.com/system/files/dam/doc/product/capacitor/ceramic/mlcc/catalog/mlcc_commercial_general_en.pdf | /usr/share/kicad/symbols/Device.kicad_sym | Value/voltage class only; exact MLCC part missing
C21-C24 | 100nF 10V | FC_Local:C_0603_1608Metric | https://product.tdk.com/system/files/dam/doc/product/capacitor/ceramic/mlcc/catalog/mlcc_commercial_general_en.pdf | /usr/share/kicad/symbols/Device.kicad_sym | Value/voltage class only; exact MLCC part missing
R1-R2,R6,R9-R10 | 10k | FC_Local:R_0402_1005Metric | https://www.vishay.com/docs/20035/crcwce3.pdf | /usr/share/kicad/symbols/Device.kicad_sym | Value/tolerance only; exact resistor part missing
R3-R4 | 100k 1% | FC_Local:R_0402_1005Metric | https://www.vishay.com/docs/20035/crcwce3.pdf | /usr/share/kicad/symbols/Device.kicad_sym | Value/tolerance only; exact resistor part missing
R5 | 10R | FC_Local:R_0402_1005Metric | https://www.vishay.com/docs/20035/crcwce3.pdf | /usr/share/kicad/symbols/Device.kicad_sym | Value only; exact resistor part missing
R7-R8 | 5.1k 1% | FC_Local:R_0402_1005Metric | https://www.vishay.com/docs/20035/crcwce3.pdf | /usr/share/kicad/symbols/Device.kicad_sym | USB CC value; exact resistor part missing
R11,R15,R17,R19,R21 | 100R | FC_Local:R_0402_1005Metric | https://www.vishay.com/docs/20035/crcwce3.pdf | /usr/share/kicad/symbols/Device.kicad_sym | Value only; exact resistor part missing
R12 | 1.8M 1% | FC_Local:R_0402_1005Metric | https://www.vishay.com/docs/20035/crcwce3.pdf | /usr/share/kicad/symbols/Device.kicad_sym | Boost feedback value; exact resistor part missing
R13 | 200k 1% | FC_Local:R_0402_1005Metric | https://www.vishay.com/docs/20035/crcwce3.pdf | /usr/share/kicad/symbols/Device.kicad_sym | Boost feedback value; exact resistor part missing
R16,R18,R20,R22 | 100k | FC_Local:R_0402_1005Metric | https://www.vishay.com/docs/20035/crcwce3.pdf | /usr/share/kicad/symbols/Device.kicad_sym | Value only; exact resistor part missing
R23-R24 | 4.7k | FC_Local:R_0402_1005Metric | https://www.vishay.com/docs/20035/crcwce3.pdf | /usr/share/kicad/symbols/Device.kicad_sym | I2C pull-up value; exact resistor part missing

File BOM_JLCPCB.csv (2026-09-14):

Comment | Designator | Footprint
ESP32-WROOM-32 (8MB) | U1 | FC_Local:ESP32
22uF 10V X5R | C1 | FC_Local:C_0805_2012Metric
100nF | C2 | FC_Local:C_0402_1005Metric
10k | R1 | FC_Local:R_0402_1005Metric
1uF | C3 | FC_Local:C_0603_1608Metric
10k | R2 | FC_Local:R_0402_1005Metric
100k 1% | R3 | FC_Local:R_0402_1005Metric
100k 1% | R4 | FC_Local:R_0402_1005Metric
100nF | C4 | FC_Local:C_0402_1005Metric
MPU-6500 | U2 | FC_Local:MPU6500
10R | R5 | FC_Local:R_0402_1005Metric
100nF | C5 | FC_Local:C_0402_1005Metric
10nF | C6 | FC_Local:C_0402_1005Metric
100nF | C7 | FC_Local:C_0402_1005Metric
1uF | C8 | FC_Local:C_0402_1005Metric
10k | R6 | FC_Local:R_0402_1005Metric
USB4105-GF-A | J1 | FC_Local:USB_C
CH340C | U3 | FC_Local:CH340C
100nF | C9 | FC_Local:C_0402_1005Metric
5.1k 1% | R7 | FC_Local:R_0402_1005Metric
5.1k 1% | R8 | FC_Local:R_0402_1005Metric
USBLC6-2SC6 | U4 | FC_Local:SOT-23-6
1uF 10V | C11 | FC_Local:C_0603_1608Metric
MMBT3904 | Q5 | FC_Local:MMBT3904
MMBT3904 | Q6 | FC_Local:MMBT3904
10k | R9 | FC_Local:R_0402_1005Metric
10k | R10 | FC_Local:R_0402_1005Metric
MTF-01P SH1.0 | J2 | FC_Local:JST_SH_SM04B-SRSS-TB_1x04-1MP_P1.00mm_Horizontal
I2C | J8 | FC_Local:Header_1x04_P2.54mm
UART1 | J9 | FC_Local:Header_1x04_P2.54mm
4.7k | R23 | FC_Local:R_0402_1005Metric
4.7k | R24 | FC_Local:R_0402_1005Metric
BAT 1S | J3 | FC_Local:Battery_Wire_Pads
SS16 | D5 | FC_Local:SS16
SS16 | D6 | FC_Local:SS16
TPS63001DRCR | U5 | FC_Local:Texas_DRC0010J
2.2uH VLF4012-2R2M1R5 | L1 | FC_Local:L_VLF4012
10uF 10V X5R | C12 | FC_Local:C_0805_2012Metric
10uF 10V X5R | C13 | FC_Local:C_0805_2012Metric
100R | R11 | FC_Local:R_0402_1005Metric
100nF | C15 | FC_Local:C_0402_1005Metric
TPS61070DDCR | U6 | FC_Local:SOT-23-6
4.7uH >=1A shielded | L2 | FC_Local:L_4x4
22uF 10V X5R | C17 | FC_Local:C_0805_2012Metric
1.8M 1% | R12 | FC_Local:R_0402_1005Metric
200k 1% | R13 | FC_Local:R_0402_1005Metric
100nF | C18 | FC_Local:C_0402_1005Metric
47uF 10V X5R | C19 | FC_Local:C_1206_3216Metric
AO3400 | Q1 | FC_Local:AO3400
SS16 | D1 | FC_Local:SS16
M1 + / - | J4 | FC_Local:Motor_Wire_Pads
100R | R15 | FC_Local:R_0402_1005Metric
100k | R16 | FC_Local:R_0402_1005Metric
100nF 10V | C21 | FC_Local:C_0603_1608Metric
AO3400 | Q2 | FC_Local:AO3400
SS16 | D2 | FC_Local:SS16
M2 + / - | J5 | FC_Local:Motor_Wire_Pads
100R | R17 | FC_Local:R_0402_1005Metric
100k | R18 | FC_Local:R_0402_1005Metric
100nF 10V | C22 | FC_Local:C_0603_1608Metric
AO3400 | Q3 | FC_Local:AO3400
SS16 | D3 | FC_Local:SS16
M3 + / - | J6 | FC_Local:Motor_Wire_Pads
100R | R19 | FC_Local:R_0402_1005Metric
100k | R20 | FC_Local:R_0402_1005Metric
100nF 10V | C23 | FC_Local:C_0603_1608Metric
AO3400 | Q4 | FC_Local:AO3400
SS16 | D4 | FC_Local:SS16
M4 + / - | J7 | FC_Local:Motor_Wire_Pads
100R | R21 | FC_Local:R_0402_1005Metric
100k | R22 | FC_Local:R_0402_1005Metric
100nF 10V | C24 | FC_Local:C_0603_1608Metric

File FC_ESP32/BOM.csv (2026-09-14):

Reference | Value | Footprint | Side | Notes
U1 | ESP32-WROOM-32 (8MB) | FC_Local:ESP32 | F
C1 | 22uF 10V X5R | FC_Local:C_0805_2012Metric | F
C2 | 100nF | FC_Local:C_0402_1005Metric | F
R1 | 10k | FC_Local:R_0402_1005Metric | F
C3 | 1uF | FC_Local:C_0603_1608Metric | F
R2 | 10k | FC_Local:R_0402_1005Metric | F
R3 | 100k 1% | FC_Local:R_0402_1005Metric | F
R4 | 100k 1% | FC_Local:R_0402_1005Metric | F
C4 | 100nF | FC_Local:C_0402_1005Metric | F
U2 | MPU-6500 | FC_Local:MPU6500 | F
R5 | 10R | FC_Local:R_0402_1005Metric | F
C5 | 100nF | FC_Local:C_0402_1005Metric | F
C6 | 10nF | FC_Local:C_0402_1005Metric | F
C7 | 100nF | FC_Local:C_0402_1005Metric | F
C8 | 1uF | FC_Local:C_0402_1005Metric | F
R6 | 10k | FC_Local:R_0402_1005Metric | F
J1 | USB4105-GF-A | FC_Local:USB_C | F
U3 | CH340C | FC_Local:CH340C | F
C9 | 100nF | FC_Local:C_0402_1005Metric | F
R7 | 5.1k 1% | FC_Local:R_0402_1005Metric | F
R8 | 5.1k 1% | FC_Local:R_0402_1005Metric | F
U4 | USBLC6-2SC6 | FC_Local:SOT-23-6 | F
C11 | 1uF 10V | FC_Local:C_0603_1608Metric | F
Q5 | MMBT3904 | FC_Local:MMBT3904 | F
Q6 | MMBT3904 | FC_Local:MMBT3904 | F
R9 | 10k | FC_Local:R_0402_1005Metric | F
R10 | 10k | FC_Local:R_0402_1005Metric | F
J2 | MTF-01P SH1.0 | FC_Local:JST_SH_SM04B-SRSS-TB_1x04-1MP_P1.00mm_Horizontal | F | Pin 3 to sensor Rx; pin 4 to sensor Tx. Verify cable orientation.
J8 | I2C | FC_Local:Header_1x04_P2.54mm | F
J9 | UART1 | FC_Local:Header_1x04_P2.54mm | F
R23 | 4.7k | FC_Local:R_0402_1005Metric | F
R24 | 4.7k | FC_Local:R_0402_1005Metric | F
J3 | BAT 1S | FC_Local:Battery_Wire_Pads | F
D5 | SS16 | FC_Local:SS16 | F
D6 | SS16 | FC_Local:SS16 | F
U5 | TPS63001DRCR | FC_Local:Texas_DRC0010J | F
L1 | 2.2uH VLF4012-2R2M1R5 | FC_Local:L_VLF4012 | F
C12 | 10uF 10V X5R | FC_Local:C_0805_2012Metric | F
C13 | 10uF 10V X5R | FC_Local:C_0805_2012Metric | F
R11 | 100R | FC_Local:R_0402_1005Metric | F
C15 | 100nF | FC_Local:C_0402_1005Metric | F
U6 | TPS61070DDCR | FC_Local:SOT-23-6 | F
L2 | 4.7uH >=1A shielded | FC_Local:L_4x4 | F | 4x4 land; choose matching inductor before ordering
C17 | 22uF 10V X5R | FC_Local:C_0805_2012Metric | F
R12 | 1.8M 1% | FC_Local:R_0402_1005Metric | F
R13 | 200k 1% | FC_Local:R_0402_1005Metric | F
C18 | 100nF | FC_Local:C_0402_1005Metric | F
C19 | 47uF 10V X5R | FC_Local:C_1206_3216Metric | F
Q1 | AO3400 | FC_Local:AO3400 | F
D1 | SS16 | FC_Local:SS16 | F
J4 | M1 + / - | FC_Local:Motor_Wire_Pads | F
R15 | 100R | FC_Local:R_0402_1005Metric | F
R16 | 100k | FC_Local:R_0402_1005Metric | F
C21 | 100nF 10V | FC_Local:C_0603_1608Metric | F
Q2 | AO3400 | FC_Local:AO3400 | F
D2 | SS16 | FC_Local:SS16 | F
J5 | M2 + / - | FC_Local:Motor_Wire_Pads | F
R17 | 100R | FC_Local:R_0402_1005Metric | F
R18 | 100k | FC_Local:R_0402_1005Metric | F
C22 | 100nF 10V | FC_Local:C_0603_1608Metric | F
Q3 | AO3400 | FC_Local:AO3400 | F
D3 | SS16 | FC_Local:SS16 | F
J6 | M3 + / - | FC_Local:Motor_Wire_Pads | F
R19 | 100R | FC_Local:R_0402_1005Metric | F
R20 | 100k | FC_Local:R_0402_1005Metric | F
C23 | 100nF 10V | FC_Local:C_0603_1608Metric | F
Q4 | AO3400 | FC_Local:AO3400 | F
D4 | SS16 | FC_Local:SS16 | F
J7 | M4 + / - | FC_Local:Motor_Wire_Pads | F
R21 | 100R | FC_Local:R_0402_1005Metric | F
R22 | 100k | FC_Local:R_0402_1005Metric | F
C24 | 100nF 10V | FC_Local:C_0603_1608Metric | F

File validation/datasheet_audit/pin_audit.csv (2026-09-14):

Reference | Value | Pad | Schematic_pin_name | Schematic_net | PCB_net | Independent_expected_net | X_mm | Y_mm | Footprint_angle_deg | Side
C1 | 22uF 10V X5R | 1 |  | +3V3 | +3V3 |  | 85.05 | 82.7 | 0.0 | F
C1 | 22uF 10V X5R | 2 |  | GND | GND |  | 86.95 | 82.7 | 0.0 | F
C11 | 1uF 10V | 1 |  | VBUS | VBUS |  | 105.725 | 109.75 | 0.0 | F
C11 | 1uF 10V | 2 |  | GND | GND |  | 107.275 | 109.75 | 0.0 | F
C12 | 10uF 10V X5R | 1 |  | VSYS | VSYS |  | 111.05 | 86.0 | 0.0 | F
C12 | 10uF 10V X5R | 2 |  | GND | GND |  | 112.95 | 86.0 | 0.0 | F
C13 | 10uF 10V X5R | 1 |  | +3V3 | +3V3 |  | 111.05 | 83.75 | 0.0 | F
C13 | 10uF 10V X5R | 2 |  | GND | GND |  | 112.95 | 83.75 | 0.0 | F
C15 | 100nF | 1 |  | VINA | VINA |  | 110.52 | 92.0 | 0.0 | F
C15 | 100nF | 2 |  | GND | GND |  | 111.48 | 92.0 | 0.0 | F
C17 | 22uF 10V X5R | 1 |  | +5V_FLOW | +5V_FLOW |  | 80.3 | 84.5 | 0.0 | F
C17 | 22uF 10V X5R | 2 |  | GND | GND |  | 82.2 | 84.5 | 0.0 | F
C18 | 100nF | 1 |  | +5V_FLOW | +5V_FLOW |  | 108.52 | 108.3 | 0.0 | F
C18 | 100nF | 2 |  | GND | GND |  | 109.48 | 108.3 | 0.0 | F
C19 | 47uF 10V X5R | 1 |  | VBAT | VBAT |  | 109.725 | 115.7 | 0.0 | F
C19 | 47uF 10V X5R | 2 |  | GND | GND |  | 112.675 | 115.7 | 0.0 | F
C2 | 100nF | 1 |  | +3V3 | +3V3 |  | 88.22 | 85.4 | 0.0 | F
C2 | 100nF | 2 |  | GND | GND |  | 89.18 | 85.4 | 0.0 | F
C21 | 100nF 10V | 1 |  | VBAT | VBAT |  | 72.75 | 70.025 | 90.0 | F
C21 | 100nF 10V | 2 |  | M1_NEG | M1_NEG |  | 72.75 | 68.475 | 90.0 | F
C22 | 100nF 10V | 1 |  | VBAT | VBAT |  | 121.975 | 73.75 | 0.0 | F
C22 | 100nF 10V | 2 |  | M2_NEG | M2_NEG |  | 123.525 | 73.75 | 0.0 | F
C23 | 100nF 10V | 1 |  | VBAT | VBAT |  | 120.25 | 124.525 | 90.0 | F
C23 | 100nF 10V | 2 |  | M3_NEG | M3_NEG |  | 120.25 | 122.975 | 90.0 | F
C24 | 100nF 10V | 1 |  | VBAT | VBAT |  | 76.475 | 126.25 | 0.0 | F
C24 | 100nF 10V | 2 |  | M4_NEG | M4_NEG |  | 78.025 | 126.25 | 0.0 | F
C3 | 1uF | 1 |  | EN | EN |  | 89.325 | 93.25 | 180.0 | F
C3 | 1uF | 2 |  | GND | GND |  | 87.775 | 93.25 | 180.0 | F
C4 | 100nF | 1 |  | VBAT_ADC | VBAT_ADC |  | 88.67 | 90.7 | 0.0 | F
C4 | 100nF | 2 |  | GND | GND |  | 89.63 | 90.7 | 0.0 | F
C5 | 100nF | 1 |  | +3V3_IMU | +3V3_IMU |  | 102.32 | 109.7 | 0.0 | F
C5 | 100nF | 2 |  | GND | GND |  | 103.28 | 109.7 | 0.0 | F
C6 | 10nF | 1 |  | +3V3_IMU | +3V3_IMU |  | 96.22 | 106.0 | 0.0 | F
C6 | 10nF | 2 |  | GND | GND |  | 97.18 | 106.0 | 0.0 | F
C7 | 100nF | 1 |  | REGOUT | REGOUT |  | 94.22 | 106.9 | 0.0 | F
C7 | 100nF | 2 |  | GND | GND |  | 95.18 | 106.9 | 0.0 | F
C8 | 1uF | 1 |  | +3V3_IMU | +3V3_IMU |  | 96.22 | 104.75 | 0.0 | F
C8 | 1uF | 2 |  | GND | GND |  | 97.18 | 104.75 | 0.0 | F
C9 | 100nF | 1 |  | +3V3 | +3V3 |  | 93.52 | 104.75 | 0.0 | F
C9 | 100nF | 2 |  | GND | GND |  | 94.48 | 104.75 | 0.0 | F
D1 | SS16 | 1 |  | VBAT | VBAT | VBAT | 78.0 | 81.615 | 90.0 | F
D1 | SS16 | 2 |  | M1_NEG | M1_NEG | M1_NEG | 78.0 | 77.385 | 90.0 | F
D2 | SS16 | 1 |  | VBAT | VBAT | VBAT | 118.385 | 78.0 | 0.0 | F
D2 | SS16 | 2 |  | M2_NEG | M2_NEG | M2_NEG | 122.615 | 78.0 | 0.0 | F
D3 | SS16 | 1 |  | VBAT | VBAT | VBAT | 122.75 | 123.365 | 90.0 | F
D3 | SS16 | 2 |  | M3_NEG | M3_NEG | M3_NEG | 122.75 | 119.135 | 90.0 | F
D4 | SS16 | 1 |  | VBAT | VBAT | VBAT | 76.635 | 122.75 | 0.0 | F
D4 | SS16 | 2 |  | M4_NEG | M4_NEG | M4_NEG | 80.865 | 122.75 | 0.0 | F
D5 | SS16 | 1 |  | VSYS | VSYS | VSYS | 82.5 | 118.115 | 90.0 | F
D5 | SS16 | 2 |  | VBAT | VBAT | VBAT | 82.5 | 113.885 | 90.0 | F
D6 | SS16 | 1 |  | VSYS | VSYS | VSYS | 88.5 | 102.615 | 90.0 | F
D6 | SS16 | 2 |  | VBUS | VBUS | VBUS | 88.5 | 98.385 | 90.0 | F
H1 |  |  |  |  |  |  | 66.599999 | 66.599999 | 0.0 | F
H2 |  |  |  |  |  |  | 133.4 | 66.599999 | 0.0 | F
H3 |  |  |  |  |  |  | 133.4 | 133.4 | 0.0 | F
H4 |  |  |  |  |  |  | 66.599999 | 133.4 | 0.0 | F
J1 | USB4105-GF-A |  |  |  |  |  | 97.11 | 113.395 | 0.0 | F
J1 | USB4105-GF-A |  |  |  |  |  | 102.89 | 113.395 | 0.0 | F
J1 | USB4105-GF-A | A1 | GND_A1 | GND | GND | GND | 96.8 | 112.32 | 0.0 | F
J1 | USB4105-GF-A | A4 | VBUS_A4 | VBUS | VBUS | VBUS | 97.6 | 112.32 | 0.0 | F
J1 | USB4105-GF-A | A5 | CC1_A5 | CC1 | CC1 | CC1 | 98.75 | 112.32 | 0.0 | F
J1 | USB4105-GF-A | A6 | D+_A6 | USB_DP | USB_DP | USB_DP | 99.75 | 112.32 | 0.0 | F
J1 | USB4105-GF-A | A7 | D-_A7 | USB_DM | USB_DM | USB_DM | 100.25 | 112.32 | 0.0 | F
J1 | USB4105-GF-A | A8 | SBU1_A8 | unconnected-(J1-SBU1-PadA8) |  |  | 101.25 | 112.32 | 0.0 | F
J1 | USB4105-GF-A | A9 | VBUS_A9 | VBUS | VBUS | VBUS | 102.4 | 112.32 | 0.0 | F
J1 | USB4105-GF-A | A12 | GND_A12 | GND | GND | GND | 103.2 | 112.32 | 0.0 | F
J1 | USB4105-GF-A | B1 | GND_B1 | GND | GND | GND | 103.2 | 112.32 | 0.0 | F
J1 | USB4105-GF-A | B4 | VBUS_B4 | VBUS | VBUS | VBUS | 102.4 | 112.32 | 0.0 | F
J1 | USB4105-GF-A | B5 | CC2_B5 | CC2 | CC2 | CC2 | 101.75 | 112.32 | 0.0 | F
J1 | USB4105-GF-A | B6 | D+_B6 | USB_DP | USB_DP | USB_DP | 100.75 | 112.32 | 0.0 | F
J1 | USB4105-GF-A | B7 | D-_B7 | USB_DM | USB_DM | USB_DM | 99.25 | 112.32 | 0.0 | F
J1 | USB4105-GF-A | B8 | SBU2_B8 | unconnected-(J1-SBU2-PadB8) |  |  | 98.25 | 112.32 | 0.0 | F
J1 | USB4105-GF-A | B9 | VBUS_B9 | VBUS | VBUS | VBUS | 97.6 | 112.32 | 0.0 | F
J1 | USB4105-GF-A | B12 | GND_B12 | GND | GND | GND | 96.8 | 112.32 | 0.0 | F
J1 | USB4105-GF-A | SH | SHIELD_SH | GND | GND |  | 95.68 | 112.895 | 0.0 | F
J1 | USB4105-GF-A | SH | SHIELD_SH | GND | GND |  | 95.68 | 117.075 | 0.0 | F
J1 | USB4105-GF-A | SH | SHIELD_SH | GND | GND |  | 104.32 | 112.895 | 0.0 | F
J1 | USB4105-GF-A | SH | SHIELD_SH | GND | GND |  | 104.32 | 117.075 | 0.0 | F
J2 | MTF-01P SH1.0 | 1 | Pin_1_1 | GND | GND | GND | 111.95 | 108.3 | 90.0 | F
J2 | MTF-01P SH1.0 | 2 | Pin_2_2 | +5V_FLOW | +5V_FLOW | +5V_FLOW | 111.95 | 107.3 | 90.0 | F
J2 | MTF-01P SH1.0 | 3 | Pin_3_3 | FLOW_TX | FLOW_TX | FLOW_TX | 111.95 | 106.3 | 90.0 | F
J2 | MTF-01P SH1.0 | 4 | Pin_4_4 | FLOW_RX | FLOW_RX | FLOW_RX | 111.95 | 105.3 | 90.0 | F
J2 | MTF-01P SH1.0 | MP |  |  |  |  | 115.825 | 109.6 | 90.0 | F
J2 | MTF-01P SH1.0 | MP |  |  |  |  | 115.825 | 104.0 | 90.0 | F
J3 | BAT 1S | 1 | Pin_1_1 | VBAT | VBAT | VBAT | 108.25 | 112.2 | 0.0 | F
J3 | BAT 1S | 2 | Pin_2_2 | GND | GND | GND | 112.25 | 112.2 | 0.0 | F
J4 | M1 + / - | 1 | Pin_1_1 | VBAT | VBAT | VBAT | 73.26066 | 74.66066 | 90.0 | F
J4 | M1 + / - | 2 | Pin_2_2 | M1_NEG | M1_NEG | M1_NEG | 73.26066 | 71.86066 | 90.0 | F
J5 | M2 + / - | 1 | Pin_1_1 | VBAT | VBAT | VBAT | 125.339339 | 73.26066 | 0.0 | F
J5 | M2 + / - | 2 | Pin_2_2 | M2_NEG | M2_NEG | M2_NEG | 128.139339 | 73.26066 | 0.0 | F
J6 | M3 + / - | 1 | Pin_1_1 | VBAT | VBAT | VBAT | 126.739339 | 128.139339 | 90.0 | F
J6 | M3 + / - | 2 | Pin_2_2 | M3_NEG | M3_NEG | M3_NEG | 126.739339 | 125.339339 | 90.0 | F
J7 | M4 + / - | 1 | Pin_1_1 | VBAT | VBAT | VBAT | 71.86066 | 126.739339 | 0.0 | F
J7 | M4 + / - | 2 | Pin_2_2 | M4_NEG | M4_NEG | M4_NEG | 74.66066 | 126.739339 | 0.0 | F
J8 | I2C | 1 | Pin_1_1 | +3V3 | +3V3 | +3V3 | 115.0 | 100.66 | 90.0 | F
J8 | I2C | 2 | Pin_2_2 | GND | GND | GND | 115.0 | 98.12 | 90.0 | F
J8 | I2C | 3 | Pin_3_3 | I2C_SDA | I2C_SDA | I2C_SDA | 115.0 | 95.58 | 90.0 | F
J8 | I2C | 4 | Pin_4_4 | I2C_SCL | I2C_SCL | I2C_SCL | 115.0 | 93.04 | 90.0 | F
J9 | UART1 | 1 | Pin_1_1 | +3V3 | +3V3 | +3V3 | 85.25 | 102.56 | 90.0 | F
J9 | UART1 | 2 | Pin_2_2 | GND | GND | GND | 85.25 | 100.02 | 90.0 | F
J9 | UART1 | 3 | Pin_3_3 | UART1_TX | UART1_TX | UART1_TX | 85.25 | 97.48 | 90.0 | F
J9 | UART1 | 4 | Pin_4_4 | UART1_RX | UART1_RX | UART1_RX | 85.25 | 94.94 | 90.0 | F
L1 | 2.2uH VLF4012-2R2M1R5 | 1 | 1_1 | BUCK_L1 | BUCK_L1 |  | 116.0 | 86.85 | 90.0 | F
L1 | 2.2uH VLF4012-2R2M1R5 | 2 | 2_2 | BUCK_L2 | BUCK_L2 |  | 116.0 | 83.65 | 90.0 | F
L2 | 4.7uH >=1A shielded | 1 | 1_1 | +3V3 | +3V3 |  | 85.0 | 87.75 | 90.0 | F
L2 | 4.7uH >=1A shielded | 2 | 2_2 | BOOST_SW | BOOST_SW |  | 85.0 | 84.75 | 90.0 | F
Q1 | AO3400 | 1 |  | GATE1 | GATE1 | GATE1 | 77.55 | 75.4 | 90.0 | F
Q1 | AO3400 | 2 |  | GND | GND | GND | 77.55 | 73.5 | 90.0 | F
Q1 | AO3400 | 3 |  | M1_NEG | M1_NEG | M1_NEG | 75.35 | 74.45 | 90.0 | F
Q2 | AO3400 | 1 |  | GATE2 | GATE2 | GATE2 | 124.6 | 77.55 | 0.0 | F
Q2 | AO3400 | 2 |  | GND | GND | GND | 126.5 | 77.55 | 0.0 | F
Q2 | AO3400 | 3 |  | M2_NEG | M2_NEG | M2_NEG | 125.55 | 75.35 | 0.0 | F
Q3 | AO3400 | 1 |  | GATE3 | GATE3 | GATE3 | 124.65 | 127.25 | 90.0 | F
Q3 | AO3400 | 2 |  | GND | GND | GND | 124.65 | 125.35 | 90.0 | F
Q3 | AO3400 | 3 |  | M3_NEG | M3_NEG | M3_NEG | 122.45 | 126.3 | 90.0 | F
Q4 | AO3400 | 1 |  | GATE4 | GATE4 | GATE4 | 72.75 | 124.65 | 0.0 | F
Q4 | AO3400 | 2 |  | GND | GND | GND | 74.65 | 124.65 | 0.0 | F
Q4 | AO3400 | 3 |  | M4_NEG | M4_NEG | M4_NEG | 73.7 | 122.45 | 0.0 | F
Q5 | MMBT3904 | 1 |  | BASE_EN | BASE_EN | BASE_EN | 107.3 | 105.05 | 0.0 | F
Q5 | MMBT3904 | 2 |  | RTS | RTS | RTS | 107.3 | 106.95 | 0.0 | F
Q5 | MMBT3904 | 3 |  | EN | EN | EN | 109.7 | 106.0 | 0.0 | F
Q6 | MMBT3904 | 1 |  | BASE_BOOT | BASE_BOOT | BASE_BOOT | 103.05 | 105.05 | 0.0 | F
Q6 | MMBT3904 | 2 |  | DTR | DTR | DTR | 103.05 | 106.95 | 0.0 | F
Q6 | MMBT3904 | 3 |  | BOOT | BOOT | BOOT | 105.45 | 106.0 | 0.0 | F
R1 | 10k | 1 |  | +3V3 | +3V3 |  | 87.79 | 88.25 | 0.0 | F
R1 | 10k | 2 |  | EN | EN |  | 88.81 | 88.25 | 0.0 | F
R10 | 10k | 1 |  | RTS | RTS |  | 110.5 | 101.01 | 90.0 | F
R10 | 10k | 2 |  | BASE_BOOT | BASE_BOOT |  | 110.5 | 99.99 | 90.0 | F
R11 | 100R | 1 |  | VSYS | VSYS |  | 110.49 | 93.5 | 0.0 | F
R11 | 100R | 2 |  | VINA | VINA |  | 111.51 | 93.5 | 0.0 | F
R12 | 1.8M 1% | 1 |  | +5V_FLOW | +5V_FLOW |  | 88.49 | 94.75 | 0.0 | F
R12 | 1.8M 1% | 2 |  | BOOST_FB | BOOST_FB |  | 89.51 | 94.75 | 0.0 | F
R13 | 200k 1% | 1 |  | BOOST_FB | BOOST_FB |  | 88.49 | 87.0 | 0.0 | F
R13 | 200k 1% | 2 |  | GND | GND |  | 89.51 | 87.0 | 0.0 | F
R15 | 100R | 1 |  | PWM1 | PWM1 |  | 74.7 | 77.31 | 90.0 | F
R15 | 100R | 2 |  | GATE1 | GATE1 |  | 74.7 | 76.29 | 90.0 | F
R16 | 100k | 1 |  | GATE1 | GATE1 |  | 73.45 | 77.31 | 90.0 | F
R16 | 100k | 2 |  | GND | GND |  | 73.45 | 76.29 | 90.0 | F
R17 | 100R | 1 |  | PWM2 | PWM2 |  | 124.79 | 78.8 | 0.0 | F
R17 | 100R | 2 |  | GATE2 | GATE2 |  | 125.81 | 78.8 | 0.0 | F
R18 | 100k | 1 |  | GATE2 | GATE2 |  | 122.29 | 75.8 | 0.0 | F
R18 | 100k | 2 |  | GND | GND |  | 123.31 | 75.8 | 0.0 | F
R19 | 100R | 1 |  | PWM3 | PWM3 |  | 126.3 | 123.71 | 90.0 | F
R19 | 100R | 2 |  | GATE3 | GATE3 |  | 126.3 | 122.69 | 90.0 | F
R2 | 10k | 1 |  | +3V3 | +3V3 |  | 111.49 | 102.0 | 0.0 | F
R2 | 10k | 2 |  | BOOT | BOOT |  | 112.51 | 102.0 | 0.0 | F
R20 | 100k | 1 |  | GATE3 | GATE3 |  | 125.05 | 123.71 | 90.0 | F
R20 | 100k | 2 |  | GND | GND |  | 125.05 | 122.69 | 90.0 | F
R21 | 100R | 1 |  | PWM4 | PWM4 |  | 75.69 | 124.95 | 0.0 | F
R21 | 100R | 2 |  | GATE4 | GATE4 |  | 76.71 | 124.95 | 0.0 | F
R22 | 100k | 1 |  | GATE4 | GATE4 |  | 74.94 | 120.45 | 0.0 | F
R22 | 100k | 2 |  | GND | GND |  | 75.96 | 120.45 | 0.0 | F
R23 | 4.7k | 1 |  | +3V3 | +3V3 |  | 115.24 | 90.75 | 0.0 | F
R23 | 4.7k | 2 |  | I2C_SDA | I2C_SDA |  | 116.26 | 90.75 | 0.0 | F
R24 | 4.7k | 1 |  | +3V3 | +3V3 |  | 111.74 | 94.75 | 0.0 | F
R24 | 4.7k | 2 |  | I2C_SCL | I2C_SCL |  | 112.76 | 94.75 | 0.0 | F
R3 | 100k 1% | 1 |  | VBAT | VBAT |  | 88.64 | 91.85 | 0.0 | F
R3 | 100k 1% | 2 |  | VBAT_ADC | VBAT_ADC |  | 89.66 | 91.85 | 0.0 | F
R4 | 100k 1% | 1 |  | VBAT_ADC | VBAT_ADC |  | 87.89 | 95.9 | 0.0 | F
R4 | 100k 1% | 2 |  | GND | GND |  | 88.91 | 95.9 | 0.0 | F
R5 | 10R | 1 |  | +3V3 | +3V3 |  | 102.79 | 108.45 | 0.0 | F
R5 | 10R | 2 |  | +3V3_IMU | +3V3_IMU |  | 103.81 | 108.45 | 0.0 | F
R6 | 10k | 1 |  | +3V3_IMU | +3V3_IMU |  | 104.99 | 108.3 | 0.0 | F
R6 | 10k | 2 |  | IMU_CS | IMU_CS |  | 106.01 | 108.3 | 0.0 | F
R7 | 5.1k 1% | 1 |  | CC1 | CC1 |  | 92.99 | 113.5 | 0.0 | F
R7 | 5.1k 1% | 2 |  | GND | GND |  | 94.01 | 113.5 | 0.0 | F
R8 | 5.1k 1% | 1 |  | CC2 | CC2 |  | 105.99 | 114.25 | 0.0 | F
R8 | 5.1k 1% | 2 |  | GND | GND |  | 107.01 | 114.25 | 0.0 | F
R9 | 10k | 1 |  | DTR | DTR |  | 110.5 | 98.51 | 90.0 | F
R9 | 10k | 2 |  | BASE_EN | BASE_EN |  | 110.5 | 97.49 | 90.0 | F
U1 | ESP32-WROOM-32 (8MB) | 1 | GND_1 | GND | GND | GND | 91.5 | 85.24 | 0.0 | F
U1 | ESP32-WROOM-32 (8MB) | 2 | 3V3_2 | +3V3 | +3V3 | +3V3 | 91.5 | 86.51 | 0.0 | F
U1 | ESP32-WROOM-32 (8MB) | 3 | EN_3 | EN | EN | EN | 91.5 | 87.78 | 0.0 | F
U1 | ESP32-WROOM-32 (8MB) | 4 | SENSOR_VP_4 | unconnected-(U1-SENSOR_VP-Pad4) |  |  | 91.5 | 89.05 | 0.0 | F
U1 | ESP32-WROOM-32 (8MB) | 5 | SENSOR_VN_5 | unconnected-(U1-SENSOR_VN-Pad5) |  |  | 91.5 | 90.32 | 0.0 | F
U1 | ESP32-WROOM-32 (8MB) | 6 | IO34_6 | IMU_INT | IMU_INT | IMU_INT | 91.5 | 91.59 | 0.0 | F
U1 | ESP32-WROOM-32 (8MB) | 7 | IO35_7 | VBAT_ADC | VBAT_ADC | VBAT_ADC | 91.5 | 92.86 | 0.0 | F
U1 | ESP32-WROOM-32 (8MB) | 8 | IO32_8 | UART1_RX | UART1_RX | UART1_RX | 91.5 | 94.13 | 0.0 | F
U1 | ESP32-WROOM-32 (8MB) | 9 | IO33_9 | PWM4 | PWM4 | PWM4 | 91.5 | 95.4 | 0.0 | F
U1 | ESP32-WROOM-32 (8MB) | 10 | IO25_10 | PWM1 | PWM1 | PWM1 | 91.5 | 96.67 | 0.0 | F
U1 | ESP32-WROOM-32 (8MB) | 11 | IO26_11 | PWM2 | PWM2 | PWM2 | 91.5 | 97.94 | 0.0 | F
U1 | ESP32-WROOM-32 (8MB) | 12 | IO27_12 | PWM3 | PWM3 | PWM3 | 91.5 | 99.21 | 0.0 | F
U1 | ESP32-WROOM-32 (8MB) | 13 | IO14_13 | UART1_TX | UART1_TX | UART1_TX | 91.5 | 100.48 | 0.0 | F
U1 | ESP32-WROOM-32 (8MB) | 14 | IO12_14 | unconnected-(U1-IO12-Pad14) |  |  | 91.5 | 101.75 | 0.0 | F
U1 | ESP32-WROOM-32 (8MB) | 15 | GND_15 | GND | GND | GND | 94.285 | 102.75 | 0.0 | F
U1 | ESP32-WROOM-32 (8MB) | 16 | IO13_16 | unconnected-(U1-IO13-Pad16) |  |  | 95.555 | 102.75 | 0.0 | F
U1 | ESP32-WROOM-32 (8MB) | 17 | SHD/SD2_17 | unconnected-(U1-SHD/SD2-Pad17) |  |  | 96.825 | 102.75 | 0.0 | F
U1 | ESP32-WROOM-32 (8MB) | 18 | SWP/SD3_18 | unconnected-(U1-SWP/SD3-Pad18) |  |  | 98.095 | 102.75 | 0.0 | F
U1 | ESP32-WROOM-32 (8MB) | 19 | SCS/CMD_19 | unconnected-(U1-SCS/CMD-Pad19) |  |  | 99.365 | 102.75 | 0.0 | F
U1 | ESP32-WROOM-32 (8MB) | 20 | SCL/CLK_20 | unconnected-(U1-SCL/CLK-Pad20) |  |  | 100.635 | 102.75 | 0.0 | F
U1 | ESP32-WROOM-32 (8MB) | 21 | SDO/SD0_21 | unconnected-(U1-SDO/SD0-Pad21) |  |  | 101.905 | 102.75 | 0.0 | F
U1 | ESP32-WROOM-32 (8MB) | 22 | SDI/SD1_22 | unconnected-(U1-SDI/SD1-Pad22) |  |  | 103.175 | 102.75 | 0.0 | F
U1 | ESP32-WROOM-32 (8MB) | 23 | IO15_23 | unconnected-(U1-IO15-Pad23) |  |  | 104.445 | 102.75 | 0.0 | F
U1 | ESP32-WROOM-32 (8MB) | 24 | IO2_24 | unconnected-(U1-IO2-Pad24) |  |  | 105.715 | 102.75 | 0.0 | F
U1 | ESP32-WROOM-32 (8MB) | 25 | IO0_25 | BOOT | BOOT | BOOT | 108.5 | 101.75 | 0.0 | F
U1 | ESP32-WROOM-32 (8MB) | 26 | IO4_26 | I2C_SDA | I2C_SDA | I2C_SDA | 108.5 | 100.48 | 0.0 | F
U1 | ESP32-WROOM-32 (8MB) | 27 | IO16_27 | FLOW_RX | FLOW_RX | FLOW_RX | 108.5 | 99.21 | 0.0 | F
U1 | ESP32-WROOM-32 (8MB) | 28 | IO17_28 | FLOW_TX | FLOW_TX | FLOW_TX | 108.5 | 97.94 | 0.0 | F
U1 | ESP32-WROOM-32 (8MB) | 29 | IO5_29 | unconnected-(U1-IO5-Pad29) |  |  | 108.5 | 96.67 | 0.0 | F
U1 | ESP32-WROOM-32 (8MB) | 30 | IO18_30 | SPI_SCK | SPI_SCK | SPI_SCK | 108.5 | 95.4 | 0.0 | F
U1 | ESP32-WROOM-32 (8MB) | 31 | IO19_31 | SPI_MISO | SPI_MISO | SPI_MISO | 108.5 | 94.13 | 0.0 | F
U1 | ESP32-WROOM-32 (8MB) | 32 |  |  |  |  | 108.5 | 92.86 | 0.0 | F
U1 | ESP32-WROOM-32 (8MB) | 33 | IO21_33 | IMU_CS | IMU_CS | IMU_CS | 108.5 | 91.59 | 0.0 | F
U1 | ESP32-WROOM-32 (8MB) | 34 | RXD0_34 | UART0_RX | UART0_RX | UART0_RX | 108.5 | 90.32 | 0.0 | F
U1 | ESP32-WROOM-32 (8MB) | 35 | TXD0_35 | UART0_TX | UART0_TX | UART0_TX | 108.5 | 89.05 | 0.0 | F
U1 | ESP32-WROOM-32 (8MB) | 36 | IO22_36 | I2C_SCL | I2C_SCL | I2C_SCL | 108.5 | 87.78 | 0.0 | F
U1 | ESP32-WROOM-32 (8MB) | 37 | IO23_37 | SPI_MOSI | SPI_MOSI | SPI_MOSI | 108.5 | 86.51 | 0.0 | F
U1 | ESP32-WROOM-32 (8MB) | 38 | GND_38 | GND | GND | GND | 108.5 | 85.24 | 0.0 | F
U1 | ESP32-WROOM-32 (8MB) | 39 | GND_39 | GND | GND | GND | 99.0 | 92.74 | 0.0 | F
U2 | MPU-6500 | 1 |  |  |  |  | 98.455 | 106.0 | 0.0 | F
U2 | MPU-6500 | 2 |  |  |  |  | 98.455 | 106.4 | 0.0 | F
U2 | MPU-6500 | 3 |  |  |  |  | 98.455 | 106.8 | 0.0 | F
U2 | MPU-6500 | 4 |  |  |  |  | 98.455 | 107.2 | 0.0 | F
U2 | MPU-6500 | 5 |  |  |  |  | 98.455 | 107.6 | 0.0 | F
U2 | MPU-6500 | 6 |  |  |  |  | 98.455 | 108.0 | 0.0 | F
U2 | MPU-6500 | 7 | AUX_CL_7 | unconnected-(U2-AUX_CL-Pad7) |  |  | 99.0 | 108.545 | 0.0 | F
U2 | MPU-6500 | 8 | VDDIO_8 | +3V3_IMU | +3V3_IMU | +3V3_IMU | 99.4 | 108.545 | 0.0 | F
U2 | MPU-6500 | 9 | AD0/SDO_9 | SPI_MISO | SPI_MISO | SPI_MISO | 99.8 | 108.545 | 0.0 | F
U2 | MPU-6500 | 10 | REGOUT_10 | REGOUT | REGOUT | REGOUT | 100.2 | 108.545 | 0.0 | F
U2 | MPU-6500 | 11 | FSYNC_11 | GND | GND | GND | 100.6 | 108.545 | 0.0 | F
U2 | MPU-6500 | 12 | INT_12 | IMU_INT | IMU_INT | IMU_INT | 101.0 | 108.545 | 0.0 | F
U2 | MPU-6500 | 13 | VDD_13 | +3V3_IMU | +3V3_IMU | +3V3_IMU | 101.545 | 108.0 | 0.0 | F
U2 | MPU-6500 | 14 |  |  |  |  | 101.545 | 107.6 | 0.0 | F
U2 | MPU-6500 | 15 |  |  |  |  | 101.545 | 107.2 | 0.0 | F
U2 | MPU-6500 | 16 |  |  |  |  | 101.545 | 106.8 | 0.0 | F
U2 | MPU-6500 | 17 |  |  |  |  | 101.545 | 106.4 | 0.0 | F
U2 | MPU-6500 | 18 | GND_18 | GND | GND | GND | 101.545 | 106.0 | 0.0 | F
U2 | MPU-6500 | 19 | RESV_1_19 | unconnected-(U2-RESV_1-Pad19) |  |  | 101.0 | 105.455 | 0.0 | F
U2 | MPU-6500 | 20 | RESV_2_20 | GND | GND | GND | 100.6 | 105.455 | 0.0 | F
U2 | MPU-6500 | 21 | AUX_DA_21 | unconnected-(U2-AUX_DA-Pad21) |  |  | 100.2 | 105.455 | 0.0 | F
U2 | MPU-6500 | 22 | NCS_22 | IMU_CS | IMU_CS | IMU_CS | 99.8 | 105.455 | 0.0 | F
U2 | MPU-6500 | 23 | SCL/SCLK_23 | SPI_SCK | SPI_SCK | SPI_SCK | 99.4 | 105.455 | 0.0 | F
U2 | MPU-6500 | 24 | SDA/SDI_24 | SPI_MOSI | SPI_MOSI | SPI_MOSI | 99.0 | 105.455 | 0.0 | F
U2 | MPU-6500 | 25 | EXP_25 | GND | GND |  | 100.0 | 107.0 | 0.0 | F
U3 | CH340C | 1 | GND_1 | GND | GND | GND | 85.25 | 105.055 | 0.0 | F
U3 | CH340C | 2 | TXD_2 | UART0_RX | UART0_RX | UART0_RX | 85.25 | 106.325 | 0.0 | F
U3 | CH340C | 3 | RXD_3 | UART0_TX | UART0_TX | UART0_TX | 85.25 | 107.595 | 0.0 | F
U3 | CH340C | 4 | V3_4 | +3V3 | +3V3 | +3V3 | 85.25 | 108.865 | 0.0 | F
U3 | CH340C | 5 | UD+_5 | USB_DP | USB_DP | USB_DP | 85.25 | 110.135 | 0.0 | F
U3 | CH340C | 6 | UD-_6 | USB_DM | USB_DM | USB_DM | 85.25 | 111.405 | 0.0 | F
U3 | CH340C | 7 | NC._7 | unconnected-(U3-NC.-Pad7) |  |  | 85.25 | 112.675 | 0.0 | F
U3 | CH340C | 8 | ~{OUT}_8 | unconnected-(U3-~{OUT}-Pad8) |  |  | 85.25 | 113.945 | 0.0 | F
U3 | CH340C | 9 | ~{CTS}_9 | unconnected-(U3-~{CTS}-Pad9) |  |  | 90.75 | 113.945 | 0.0 | F
U3 | CH340C | 10 | ~{DSR}_10 | unconnected-(U3-~{DSR}-Pad10) |  |  | 90.75 | 112.675 | 0.0 | F
U3 | CH340C | 11 | ~{RI}_11 | unconnected-(U3-~{RI}-Pad11) |  |  | 90.75 | 111.405 | 0.0 | F
U3 | CH340C | 12 | ~{DCD}_12 | unconnected-(U3-~{DCD}-Pad12) |  |  | 90.75 | 110.135 | 0.0 | F
U3 | CH340C | 13 | ~{DTR}_13 | DTR | DTR | DTR | 90.75 | 108.865 | 0.0 | F
U3 | CH340C | 14 | ~{RTS}_14 | RTS | RTS | RTS | 90.75 | 107.595 | 0.0 | F
U3 | CH340C | 15 | R232_15 | GND | GND | GND | 90.75 | 106.325 | 0.0 | F
U3 | CH340C | 16 | VCC_16 | +3V3 | +3V3 | +3V3 | 90.75 | 105.055 | 0.0 | F
U4 | USBLC6-2SC6 | 1 | I/O1_1 | USB_DM | USB_DM | USB_DM | 94.3625 | 108.3 | 0.0 | F
U4 | USBLC6-2SC6 | 2 | GND_2 | GND | GND | GND | 94.3625 | 109.25 | 0.0 | F
U4 | USBLC6-2SC6 | 3 | I/O2_3 | USB_DP | USB_DP | USB_DP | 94.3625 | 110.2 | 0.0 | F
U4 | USBLC6-2SC6 | 4 | I/O2_4 | USB_DP | USB_DP | USB_DP | 96.6375 | 110.2 | 0.0 | F
U4 | USBLC6-2SC6 | 5 | VBUS_5 | VBUS | VBUS | VBUS | 96.6375 | 109.25 | 0.0 | F
U4 | USBLC6-2SC6 | 6 | I/O1_6 | USB_DM | USB_DM | USB_DM | 96.6375 | 108.3 | 0.0 | F
U5 | TPS63001DRCR |  |  |  |  |  | 111.75 | 87.72 | 0.0 | F
U5 | TPS63001DRCR |  |  |  |  |  | 111.75 | 90.78 | 0.0 | F
U5 | TPS63001DRCR |  |  |  |  |  | 112.0 | 88.62 | 0.0 | F
U5 | TPS63001DRCR |  |  |  |  |  | 112.0 | 89.88 | 0.0 | F
U5 | TPS63001DRCR |  |  |  |  |  | 112.25 | 87.72 | 0.0 | F
U5 | TPS63001DRCR |  |  |  |  |  | 112.25 | 90.78 | 0.0 | F
U5 | TPS63001DRCR | 1 | VOUT_1 | +3V3 | +3V3 | +3V3 | 110.6 | 88.25 | 0.0 | F
U5 | TPS63001DRCR | 2 | L2_2 | BUCK_L2 | BUCK_L2 | BUCK_L2 | 110.6 | 88.75 | 0.0 | F
U5 | TPS63001DRCR | 3 | PGND_3 | GND | GND | GND | 110.6 | 89.25 | 0.0 | F
U5 | TPS63001DRCR | 4 | L1_4 | BUCK_L1 | BUCK_L1 | BUCK_L1 | 110.6 | 89.75 | 0.0 | F
U5 | TPS63001DRCR | 5 | VIN_5 | VSYS | VSYS | VSYS | 110.6 | 90.25 | 0.0 | F
U5 | TPS63001DRCR | 6 | EN_6 | VSYS | VSYS | VSYS | 113.4 | 90.25 | 0.0 | F
U5 | TPS63001DRCR | 7 | PS/SYNC_7 | VSYS | VSYS | VSYS | 113.4 | 89.75 | 0.0 | F
U5 | TPS63001DRCR | 8 | VINA_8 | VINA | VINA | VINA | 113.4 | 89.25 | 0.0 | F
U5 | TPS63001DRCR | 9 | GND_9 | GND | GND | GND | 113.4 | 88.75 | 0.0 | F
U5 | TPS63001DRCR | 10 | FB_10 | +3V3 | +3V3 | +3V3 | 113.4 | 88.25 | 0.0 | F
U5 | TPS63001DRCR | 11 | PGND_11 | GND | GND | GND | 112.0 | 89.25 | 0.0 | F
U6 | TPS61070DDCR | 1 | SW_1 | BOOST_SW | BOOST_SW | BOOST_SW | 87.1375 | 91.45 | 180.0 | F
U6 | TPS61070DDCR | 2 | GND_2 | GND | GND | GND | 87.1375 | 90.5 | 180.0 | F
U6 | TPS61070DDCR | 3 | EN_3 | +3V3 | +3V3 | +3V3 | 87.1375 | 89.55 | 180.0 | F
U6 | TPS61070DDCR | 4 | FB_4 | BOOST_FB | BOOST_FB | BOOST_FB | 84.8625 | 89.55 | 180.0 | F
U6 | TPS61070DDCR | 5 | VOUT_5 | +5V_FLOW | +5V_FLOW | +5V_FLOW | 84.8625 | 90.5 | 180.0 | F
U6 | TPS61070DDCR | 6 | VBAT_6 | +3V3 | +3V3 | +3V3 | 84.8625 | 91.45 | 180.0 | F

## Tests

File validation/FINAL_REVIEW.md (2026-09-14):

# Kiểm tra PCB cuối — 2026-09-14

> Bổ sung từ lượt review datasheet: đã phát hiện track B.Cu dưới anten mà rule DRC hiện tại không cấm, cùng các rủi ro nguồn/firmware. Xem `../BAO_CAO_KIEM_TRA_MACH.md`. Kết quả sạch bên dưới chỉ xác nhận kết nối theo bộ rule hiện tại, không xác nhận thiết kế đạt toàn bộ datasheet hoặc chắc chắn hoạt động.

## Kết quả

PCB chính: `../FC_ESP32/FC_ESP32.kicad_pcb`. Bản dự phòng: `final_routed.kicad_pcb`.

- J4–J7 dịch 1.5 mm theo hướng tâm; tâm motor và khoảng cách 66.8 mm giữ nguyên.
- J2 góc 90°, đầu cắm hướng ra cạnh phải; pin 1 GND, 2 +5V_FLOW, 3 FLOW_TX, 4 FLOW_RX.
- Đã nối mass C3 bằng hai via và điều chỉnh cục bộ VBAT B.Cu, giữ chiều rộng 1.2 mm; đã dọn ba via thừa.
- ERC, DRC, unconnected và schematic parity đều bằng 0 trên KiCad 10.0.6. Báo cáo gốc: `../FC_ESP32/validation_summary.json`.
- Audit pad motor, bề dày 0.8 mm, pin/net và chiều rộng công suất đạt: `../FC_ESP32/invariant_audit.json`.
- Đối chiếu BOM, design.json và PCB: 72 linh kiện khớp (`bom_design_audit.json`).
- Generator chạy thành công trong bản sao độc lập; vị trí, hướng, footprint, giá trị và nets khớp (`rebuild_comparison.json`, `rebuild.log`). Đã sửa nhận diện đuôi `.STEP`/`.step` trên Linux.
- Đã xem render `final_3d.png`: J2 quay ra ngoài; các model ESP32, IC, diode, MOSFET và header chính nằm đúng trên footprint. Cuộn cảm vẫn dùng model hình bao, chưa xác nhận mã đặt hàng chính xác.
- `bash firmware/tests/run.sh` đạt cả ba nhóm kiểm tra host: MPU6500, ESP-NOW/arming/failsafe, controller/fault/output limits. Chưa build lại ESP-IDF hoặc thử bay trong lượt kiểm tra này.

## Đường cấp 5 V

Netclass LogicPower vẫn 0.4 mm. +5V_FLOW có tổng 8.448 mm đường 0.18 mm tại vùng hẹp, phần còn lại 0.4 mm. Theo [nhà sản xuất MTF-01P](https://micoair.com/optical_range_sensor_mtf-01p/), cảm biến dùng 5 V và 500 mW, tương đương dòng trung bình 100 mA.

Với giả thiết đồng hoàn thiện 35 µm, cộng điện trở tất cả các đoạn của net (kể cả nhánh) cho khoảng 0.114 Ω: sụt 11.4 mV, tổn hao 1.14 mW ở 100 mA. Chi tiết trong `flow_power_review.json`. Đây là phép tính điện trở ở 20°C; không thay thế mô phỏng nhiệt, không tính via/connector/đường hồi, và không xác nhận dòng đỉnh hay khả năng nguồn boost. Cần xác nhận độ dày đồng và đo tải khi cấp nguồn thực tế.

## Giới hạn và sử dụng file

Phần dịch pad, đi dây và kiểm tra PCB đã hoàn tất. Đây chưa phải xác nhận đủ điều kiện sản xuất hoặc bay: dòng motor thực tế, nhiệt đường công suất, mã cuộn cảm, pin/cáp cảm biến và firmware điều khiển vẫn cần kiểm chứng phần cứng.

Không dùng Gerber cũ trong `../gerbers/` để đặt hàng. Chưa xuất bộ sản xuất mới trong lượt này.

Generator tạo lại bố trí và sẽ xóa routing của PCB đích. Luôn sao lưu trước khi chạy. SES hiện tại cũ hơn các sửa cuối, không import lên bản PCB đã kiểm tra. Script `../tools/repair_c3_ground.py` tái hiện sửa cuối từ snapshot trước sửa; mọi tái sinh hoặc import tiếp theo phải chạy lại ERC/DRC.

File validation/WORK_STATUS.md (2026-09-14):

# Motor-pad inset and routing

Requested change: J4–J7 move 1.5 mm radially inward, keeping motor centers at
(66.6,66.6), (133.4,66.6), (133.4,133.4), (66.6,133.4) mm. J2 remains at
90 degrees facing the right edge. Generator and placement enforce these choices.

J8 moved to the upper right central board to avoid blocking the lower-right arm.
The custom expansion headers now include their housing courtyards.

Current placement invariants: `FC_ESP32/invariant_audit.json`.
Current schematic ERC: `FC_ESP32/erc_current.json`.
Autorouting completed: `validation/routing_header.log`. Subsequent repair joined UART1_RX and lower-arm battery branches. Current authoritative remaining errors: `FC_ESP32/drc_current.json`. Upper battery branches and ground still require finishing. No routing process remains live.
Do not use older DRC summaries to certify this regenerated layout.

Persistent local runtime:
- `/usr/bin/python3`, KiCad 10 pcbnew
- `PYTHONPATH=/home/pnt/miniconda3/lib/python3.14/site-packages`
- Freerouting: `/home/pnt/.cache/fc_esp32/toolchain/freerouting-2.4.1-linux-x64/bin/freerouting`

After routing: import SES (retains locked fanout and restores project rules),
fill copper, run `tools/validate_fc.py` and `tools/audit_board.py`. Review the
physical track widths, not only netclass defaults. The R3/R4 voltage sense branch
has a separately calculated low-current exception in `tools/finish_routes.py`;
its UUID review must be recreated after every import.

Power-priority pass: all VBAT pads now connected (KiCad DRC verified before routing other nets). R3/R4 sense branch is 13.004 mm at 0.4 mm, reviewed in adc_branch_review.json. BOOST_SW fixed fanout removed due to overlap with new sense via; it must be rerouted. Live autorouter log: validation/routing_power_priority.log. Main PCB currently contains locked battery routing and fixed IC escapes; remaining nets are being routed.

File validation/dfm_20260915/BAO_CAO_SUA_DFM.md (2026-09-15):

> Cập nhật tiếp theo cùng ngày: vấn đề antenna nêu trong báo cáo này đã được sửa. Xem [báo cáo mới](../antenna_fix/BAO_CAO.md). Bộ ZIP DFM_RECHECK đã được xuất lại từ bản sửa antenna.

# Sửa PCB theo ảnh JLCDFM — 15/09/2026

## Kết quả đã kiểm tra

- KiCad 10.0.6: ERC 0, DRC 0, cảnh báo 0, kết nối hở 0, sai khác schematic/PCB 0 (`FC_ESP32/validation_summary.json`).
- Mặt sau chỉ còn **PNT**, đọc đúng chiều từ mặt dưới. Đã xem ảnh render hai mặt.
- Bộ `FC_ESP32/FC_ESP32_DFM_RECHECK.zip` có 8 lớp Gerber cần thiết và 2 file khoan riêng PTH/NPTH. Bộ `machin.zip` cũ thiếu file khoan; không dùng nó để đánh giá bản sửa.
- File khoan mới có 175 lỗ/slot mạ (163 via, 4 slot USB, 8 chân header) và 6 lỗ không mạ (4 motor Ø8,6 mm, 2 chốt USB Ø0,65 mm).
- Tất cả segment và phần đồng của via giữ nguyên. Không đổi vị trí linh kiện, số chân, net, đường kính lỗ motor, khoảng cách motor 66,8 mm hay độ dày 0,8 mm.

## Các thay đổi

1. Xóa các chữ `USB`, `1S ONLY`, `BAT+ BAT-` khỏi lớp in mặt sau; chuyển sang lớp tài liệu Dwgs.User. PNT là chữ duy nhất ở B.Silkscreen.
2. Đổi solder-mask expansion của pad từ +0,04 mm sang 0: cửa sổ mask bằng pad đồng. Bật tenting hai mặt của via và tùy chọn trừ cửa sổ mask khỏi silkscreen khi xuất Gerber.
3. Nét silkscreen tối thiểu 0,15 mm. Chuyển nét không đủ chỗ quanh linh kiện 0402 và một số dấu tròn sát pad sang F.Fab. Cắt đoạn silkscreen xâm lấn khoảng cách 0,15 mm quanh pad. Dấu định hướng trên lớp lắp ráp vẫn được giữ; cần dùng bản vẽ lắp ráp khi hàn.
4. Đặt clearance cục bộ 0,25 mm quanh lỗ motor, refill vùng GND và lưu lại PCB. Các vùng đồng trước đó chỉ cách lỗ khoảng 0,1505 mm.
5. Hai pad GND vật lý ngoài cùng USB-C (A1/B12 và A12/B1) giữ nguyên tâm và kích thước bao 0,6 × 1,15 mm, tăng bán kính góc bo từ 0,15 lên 0,24 mm. Clearance đến lỗ định vị tăng từ 0,1944 lên 0,2161 mm. Diện tích pad giảm khoảng 4,5%; đây là điều chỉnh footprint cục bộ, không phải land pattern nguyên bản của hãng.
6. Quy tắc hole-clearance chung vẫn là 0,25 mm qua `.kicad_dru`; riêng cặp đối tượng nằm trong J1 dùng 0,20 mm. Giới hạn cứng trong project là 0,20 mm để ngoại lệ có hiệu lực. Không tắt kiểm tra DRC và không giảm bề rộng đường pin/motor.
7. Các thay đổi được lưu trong `tools/build_fc.py` và thư viện FC_Local. Dùng `--finish-artwork` để áp dụng lên PCB đã đi dây mà không tái tạo và làm mất đường mạch.

## Đối chiếu với ảnh JLCDFM

| Nhóm trong ảnh | Đã xử lý/giới hạn xác nhận |
|---|---|
| Silkscreen to pad: 50 đỏ | Đã sửa hình học và cấu hình xuất; KiCad không còn lỗi silk. Chưa có số đếm JLC mới. |
| Silkscreen line width: 49 cam | Nét trên lớp in đã nâng lên ít nhất 0,15 mm. |
| Soldermask bridge: 20 đỏ, 12 cam | Đã thu expansion về 0. Audit pad danh định không tìm thấy khe mask dưới 0,10 mm; phép audit này không thay thế thuật toán JLC. |
| Mask opening exposing trace / multiple segments / negative expansion | Đã bỏ expansion pad và tent via; cần kiểm tra lại bộ Gerber mới ở JLC để đối chiếu từng marker. |
| Trace spacing / pad spacing | KiCad kiểm tra theo clearance 0,15 mm và không báo vi phạm; cảnh báo JLC có thể dùng mức mục tiêu khác. Không giảm rule để che lỗi. |
| Drill: Unanalyzed | Đã bổ sung cả PTH/NPTH, kể cả slot USB. |

Trang JLCDFM trong ảnh đã được mở thử nhưng chỉ hiện trang trắng trong trình duyệt của agent. Vì vậy **chưa chạy được DFM phía JLC trên bộ mới**, không khẳng định đã hết toàn bộ lỗi trong ảnh. Hai audit mask trước/sau cùng không có khe dưới 0,10 mm; không thể dùng số này để tuyên bố đã giải quyết 20 marker đỏ của JLC khi chưa đọc được chi tiết của chúng.

## Các điểm chưa đủ để đặt sản xuất hoặc cam kết bay

Bộ ZIP là bản **để kiểm tra DFM lại**, chưa phải phê duyệt sản xuất. Review điện trước đó còn ghi nhận đường VBAT/PWM1 trên B.Cu đi vào vùng antenna ESP32 (23 đoạn/via giao vùng; DRC hiện tại không bắt toàn bộ điều kiện antenna). Đợt sửa này giữ nguyên segment/via nên điểm đó chưa được giải quyết. L2 chưa chốt mã đặt hàng, dòng motor thực tế và thử nguồn/tải chưa có bằng chứng. Xem `BAO_CAO_KIEM_TRA_MACH.md` và `validation/datasheet_audit/antenna_audit.json`.

Không thể kết luận mạch chắc chắn hoạt động hay bay ổn định chỉ từ DRC/3D. Cần chạy lại JLCDFM, giải quyết vùng antenna và các mục điện tồn đọng, rồi kiểm tra board thật trước khi lắp cánh.

## Nguồn

- [JLCPCB: năng lực gia công PCB](https://jlcpcb.com/capabilities/pcb-capabilities): khoảng cách đồng, lỗ và kích thước nét.
- [JLCPCB: thiết kế NPTH](https://jlcpcb.com/blog/npth-design-guide): clearance đồng 0,2–0,3 mm quanh NPTH.
- [JLCPCB: solder mask và LDI](https://jlcpcb.com/blog/basic-design-of-solder-mask): cửa sổ 1:1 với pad.
- [GCT USB4105 — bản vẽ hãng](https://gct.co/files/drawings/usb4105.pdf): vị trí chân, pad và lỗ định vị. Thay đổi góc bo được mô tả ở trên.

## Tái chạy và bằng chứng

```sh
PYTHONPATH=/home/pnt/miniconda3/lib/python3.14/site-packages /usr/bin/python3 tools/build_fc.py --finish-artwork
python3 tools/export_dfm.py
PYTHONPATH=/home/pnt/miniconda3/lib/python3.14/site-packages /usr/bin/python3 tools/audit_dfm.py FC_ESP32/FC_ESP32.kicad_pcb
```

`before.kicad_pcb`/`before.kicad_pro`: bản sao trước khi sửa. `before_drc.json`: 15 vi phạm (bao gồm zone chưa refill đúng). `after_drc.json`: sạch. `copper_comparison.json`: segment/via đồng không đổi. `geometry_after.json`: mask và chữ sau. `package_manifest.json`: SHA-256 của PCB và từng file xuất. `bottom.png`/`top.png`: ảnh kiểm tra hai mặt.

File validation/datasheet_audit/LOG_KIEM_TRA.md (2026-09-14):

# Log kiểm tra thiết kế theo datasheet

Thực hiện ngày 14/09/2026 trên `/home/pnt/FC_ESP32`. Timestamp UTC và hash nằm trong `review_manifest.json`/`audit.json`. Báo cáo giải thích: `../../BAO_CAO_KIEM_TRA_MACH.md`.

## Các bước đã thực hiện

| Bước | Thao tác / dữ liệu | Kết quả |
|---|---|---|
| 01 | Đọc AGENTS.md, BOM 72 linh kiện, generator, main.c và toàn bộ module MPU/command/radio/controller/PID/Kconfig | Hoàn tất đọc và rà soát; không sửa schematic/PCB/firmware |
| 02 | `pdftotext -layout` cho PDF trong data_sheet | Text local được lưu tại thư mục log này |
| 03 | Xem hình pinout AO3400, MMBT3904 và USB4105 bằng render PDF | Các PNG `ao3400.png`, `mmbt3904.png`, `usb4105.png`; có cảnh báo font cache của môi trường nhưng ảnh tạo thành công và đã xem |
| 04 | Tra nguồn chính thức ST USBLC6, Espressif ESP32 + PCB guide, MicoAir MTF-01P, GCT USB4105 | Dẫn nguồn trong báo cáo; không dùng trang bán hàng để xác nhận chân IC |
| 05 | Xuất netlist mới bằng `kicad-cli sch export netlist ... --format kicadxml` | `fresh.net`, exit 0 |
| 06 | `tools/review_design.py`, mapping độc lập từ datasheet/yêu cầu | 135 pad instances khớp expected; 279 pad instances ghi CSV; `connectivity_pass=true` |
| 07 | So các chân NC/reserved/flash và macro GPIO firmware | Không thấy sai trong tập kiểm tra; U2 exposed pad 25 được ghi là chưa đủ chứng cứ |
| 08 | Đo segment/width và vị trí cụm nguồn từ PCB | `geometry.json`; phát hiện routing feedback/nguồn cần tối ưu, netclass không bảo đảm chiều rộng tất cả đoạn |
| 09 | Đọc rule area anten và kiểm tra đồng độc lập theo vùng U1 thực tế | **FAIL**: 23 đoạn giao vùng, VBAT/PWM1 B.Cu, diện tích hợp giao 2.822775 mm²; `antenna_audit.json` chứa UUID |
| 10 | `python3 tools/validate_fc.py` | exit 0; ERC=0, DRC=0, unconnected=0, parity=0; `erc_drc.log` và các JSON snapshot |
| 11 | `tools/audit_board.py --output .../invariants.json` | exit 0; motor pitch/pad inward/J2/thickness/netclass đạt |
| 12 | `bash firmware/tests/run.sh` | exit 0; MPU6500, ESP-NOW logic, controller tests đạt với ASan/UBSan; `firmware_tests.log` |
| 13 | Kiểm tra vị trí SDK ESP-IDF trước đây và thư mục dự án | Không thấy SDK/toolchain hiện hành ở các vị trí đã dùng; không chạy full ESP-IDF build, không nạp ESP32 |
| 14 | `kicad-cli pcb render` cho top/bottom, 1800×1800, quality high | exit 0 cả hai; `render_top.log`, `render_bottom.log`; đã xem trực tiếp PNG mới |
| 15 | Hoàn thiện báo cáo, bảng chân, sơ đồ khối, feature matrix và việc cần đo trên mạch thật | `BAO_CAO_KIEM_TRA_MACH.md`; chưa có phép đo vật lý |
| 16 | Chạy lại script review sau khi thêm gate anten | exit 1 **có chủ đích do phát hiện thiết kế**, không phải exception; pin mapping PASS, anten FAIL |

## Diễn giải pass/fail

DRC hiện tại không cấm track B.Cu ở anten; vì thế DRC PASS và anten FAIL không mâu thuẫn. Không vô hiệu hóa thêm rule hoặc thêm exclusion để làm báo cáo sạch. Script audit cũ chưa kiểm tra anten đầy đủ; kết quả pass của nó cũng không chứng minh RF đúng.

Script `review_design.py` không tự sửa phần cứng. Mapping chân/net được kiểm tra bằng expected độc lập cho các chân trọng yếu, còn những kết nối linh kiện thụ động được đối chiếu giữa design.json, netlist mới và PCB. Kiểm tra này không chứng minh mọi giá trị linh kiện đáp ứng mọi tải. Các pin/đặc tính chưa xác nhận và các giới hạn đo được ghi rõ trong báo cáo.

Không thực hiện: thay linh kiện, đi lại PCB, sửa firmware, build ESP-IDF toàn bộ, flash, bật motor, mô phỏng SPICE/transient, thermal/EMC test, đo RF, kiểm tra collision bằng assembly đủ motor/cánh/pin/cáp hoặc đặt hàng sản xuất.

## File cần dùng tiếp

- `audit.json`: trạng thái pin/anten và hash nguồn.
- `pin_audit.csv`: bảng toàn bộ pad schematic–PCB, tọa độ và hướng.
- `antenna_audit.json`: lỗi anten có UUID để định vị trong PCB.
- `geometry.json`: chiều dài/chiều rộng thực và tọa độ linh kiện.
- `erc_current.json`, `drc_current.json`, `validation_summary.json`: snapshot kiểm tra KiCad lần này.
- `firmware_tests.log`: các nhóm host test đã chạy.
- `top_3d.png`, `bottom_3d.png`: hai ảnh 3D đã kiểm tra.
- `review_manifest.json`: kết luận chưa phê duyệt phần cứng và hash artifact.

Đầu việc tiếp theo: RF-01, PWR-01, CFG-01 và BOM/assembly trong báo cáo chính. Không bắt đầu bằng việc bật `CONFIG_FC_ENABLE_MOTORS` để thử bay.

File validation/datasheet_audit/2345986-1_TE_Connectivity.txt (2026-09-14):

                                                                  A1   A2   A3   A4    A5    A6    A7    A8    A9     A10 A11 A12

                                                                B12 B11 B10 B9        B8    B7    B6    B5    B4 B3     B2   B1

B12 B11 B10 B9      B8 B7    B6    B5    B4 B3     B2   B1

  A1   A2   A3 A4    A5     A6    A7    A8   A9   A10 A11 A12

Mouser Electronics

Authorized Distributor

Click to View Pricing, Inventory, Delivery & Lifecycle Information:

TE Connectivity:
 2345986-1

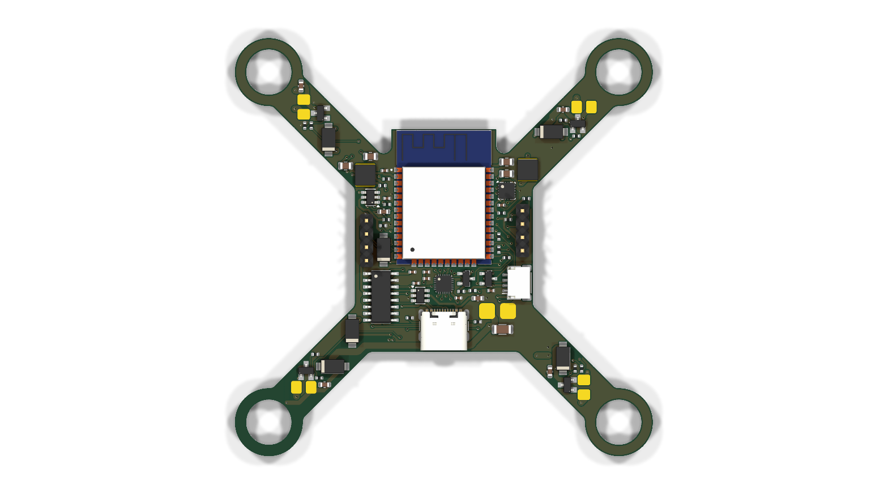
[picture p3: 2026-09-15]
validation/dfm_20260915/top.png

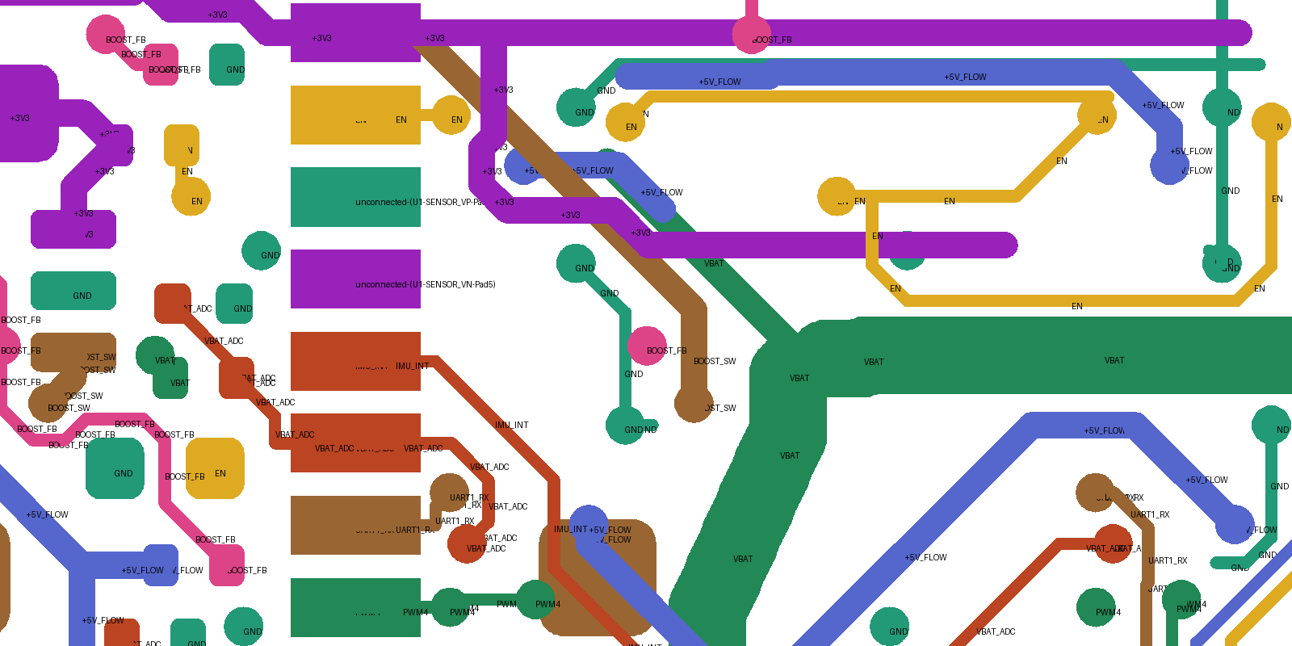
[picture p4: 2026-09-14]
validation/c3_route.png

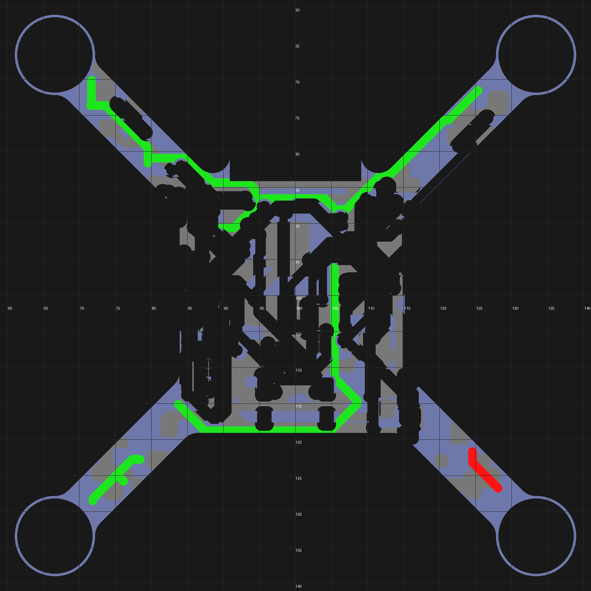
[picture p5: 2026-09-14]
validation/route_space_1.png

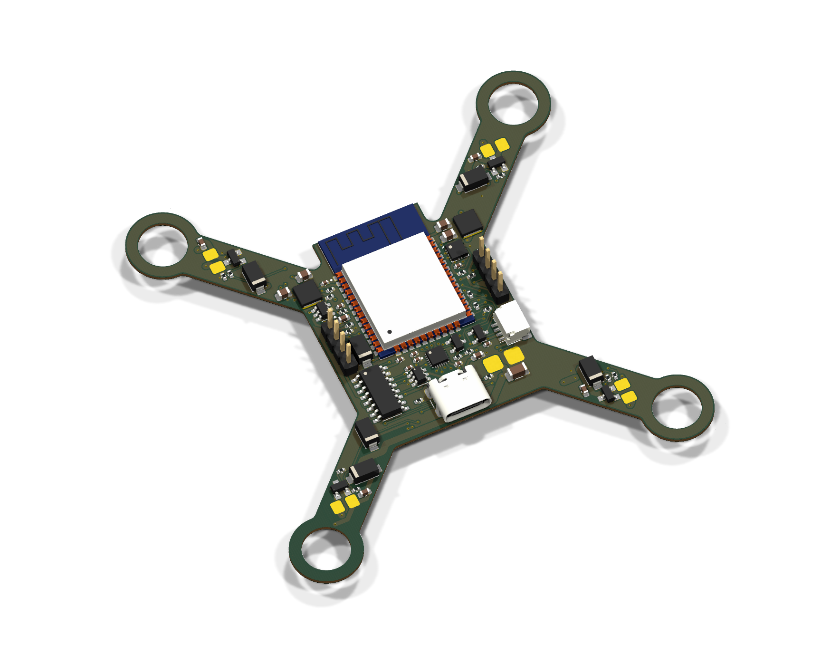
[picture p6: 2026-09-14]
validation/final_3d.png

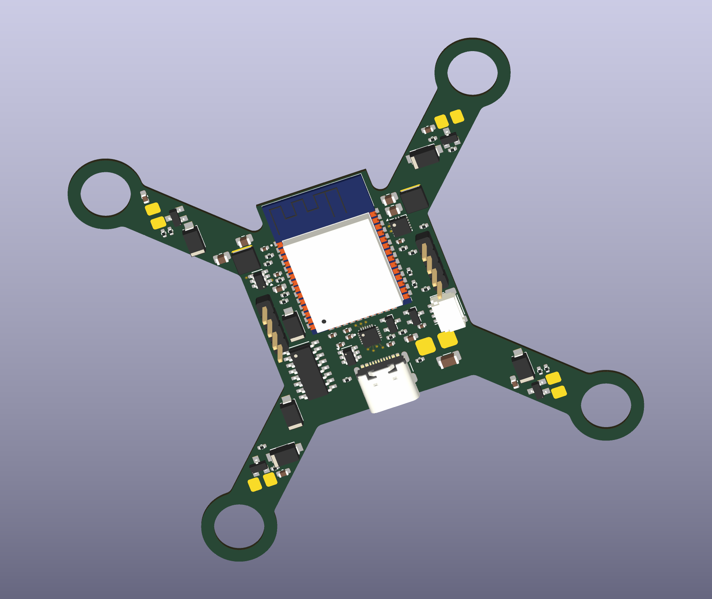
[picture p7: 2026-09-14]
validation/placement_3d.png

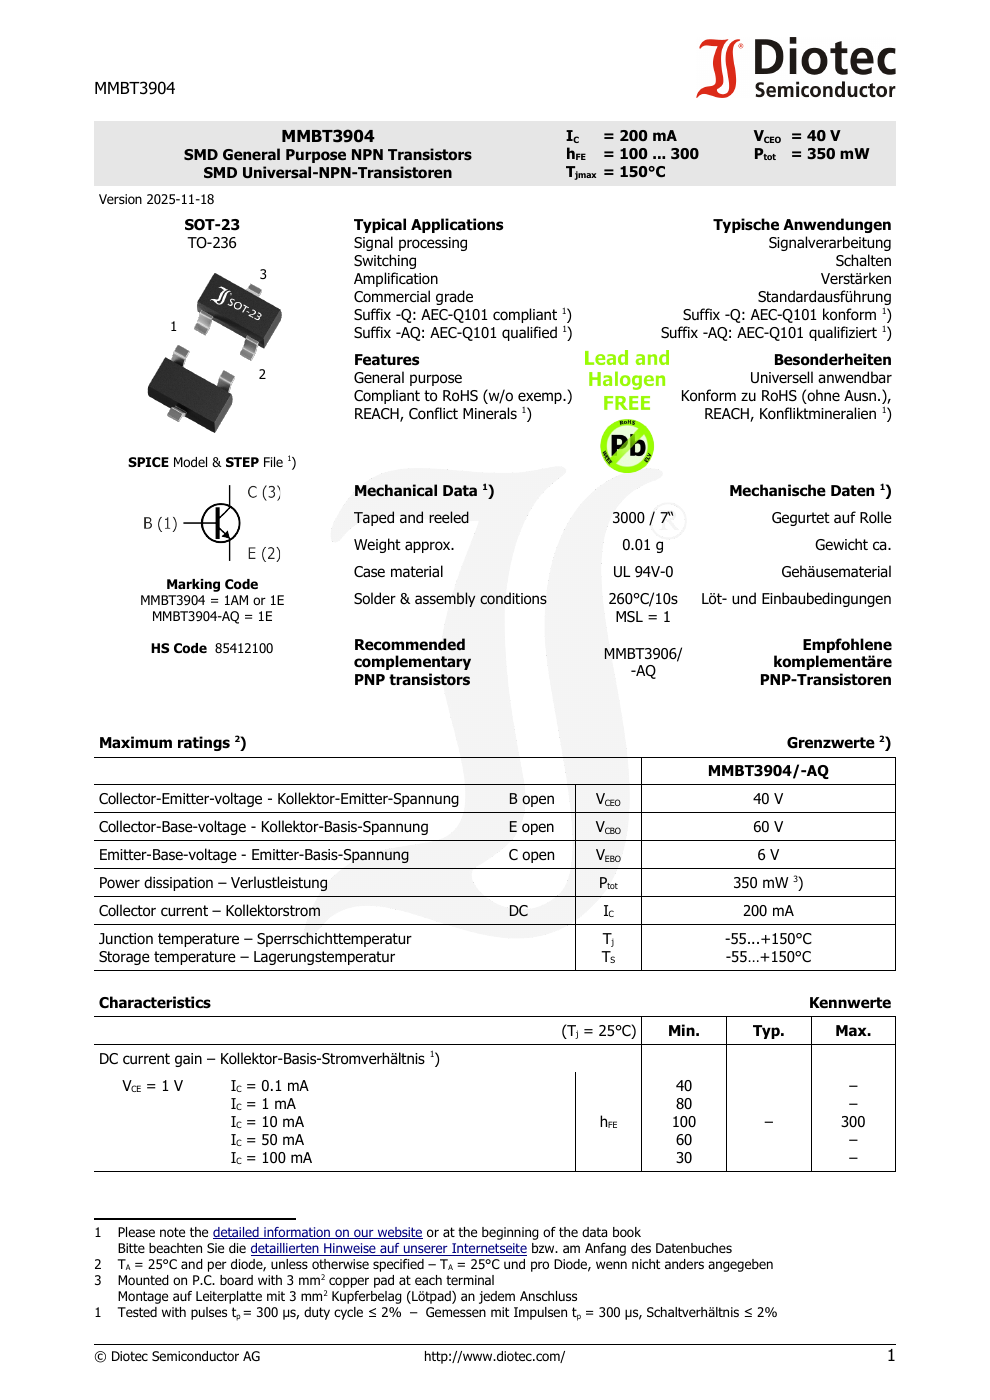
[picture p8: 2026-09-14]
validation/datasheet_audit/mmbt3904.png

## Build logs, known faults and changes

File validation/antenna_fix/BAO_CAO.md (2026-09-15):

# Sửa vùng antenna ESP32 — 15/09/2026

Đã sửa phần copper xâm lấn envelope antenna của U1: X=91–109 mm, Y=77,75–84,05 mm.

## Thay đổi

- Gỡ 21 segment VBAT và 2 segment PWM1 xâm lấn vùng antenna; giữ các đoạn còn lại.
- Nối lại VBAT bằng đường 1,2 mm ngoài vùng antenna, không giảm bề rộng nguồn. Router thêm 34 segment.
- Nối lại PWM1 bằng đường 0,18 mm ngoài vùng antenna. Router thêm 103 segment; mỗi net trở lại một nhóm đồng liên thông.
- Thêm rule area `ESP32_ANTENNA_ALL_COPPER` trên cả F.Cu và B.Cu: cấm track, via, pad và zone fill. Module U1 được phép nằm trên vùng này vì antenna là một phần module.
- Refill GND để loại bỏ đồng đổ trong antenna. Audit mở rộng phát hiện bản trước còn 1 vùng đồng xâm lấn ngoài 23 segment đã biết.
- Cập nhật generator `build_fc.py` để tạo lại keepout; cập nhật router để tính cả nửa bề rộng track và bán kính via khi né vùng này.
- Thêm `audit_antenna.py` kiểm tra độc lập track/via, pad, đồng đổ đã fill và các cờ cấm trên hai lớp. Export Gerber bị chặn nếu audit không đạt hoặc SHA-256 không khớp PCB hiện tại.

## Kết quả kiểm tra

| Kiểm tra | Kết quả |
|---|---|
| Audit bản trước khi sửa | Không đạt: 23 track/via và 1 zone xâm lấn; chưa có keepout bảo vệ đủ hai lớp |
| Audit bản đã sửa | Đạt: 0 đối tượng đồng xâm lấn, keepout đủ hai lớp |
| ERC | 0 vi phạm |
| DRC | 0 lỗi, 0 cảnh báo |
| Kết nối hở / schematic parity | 0 / 0 |
| Kiểm tra pin theo datasheet và yêu cầu đang lưu | Đạt |
| Kiểm tra kích thước, J2, pad motor và bề rộng đường nguồn | Đạt |
| Kiểm tra ảnh render mặt dưới | PNT đọc đúng chiều; không còn đường ngang đi xuyên phần antenna |

Không thay đổi vị trí linh kiện, số chân, cổng J2, khoảng cách motor 66,8 mm, lỗ motor Ø8,6 mm hoặc board dày 0,8 mm. Bộ Gerber và hai file khoan được xuất lại sau sửa tại `FC_ESP32/FC_ESP32_DFM_RECHECK.zip`.

Các file chứng cứ trong thư mục này: `before.kicad_pcb`, `removed.json`, `route_vbat.log`, `route_pwm1.log`, `regression_before.json`, `antenna_geometry.json`, `invariants.json`, `erc_drc.log`, `package_manifest.json`, `bottom.png`.

## Tái kiểm tra và xuất

Chạy từ thư mục gốc dự án:

```sh
PYTHONPATH=/home/pnt/miniconda3/lib/python3.14/site-packages /usr/bin/python3 tools/audit_antenna.py > validation/antenna_fix/antenna_geometry.json
python3 tools/export_dfm.py
```

`prepare_antenna_fix.py` chỉ dùng khi thực sự cần gỡ và đi lại đoạn vi phạm; không cần chạy lại trên bản đã sạch.

Đây là xác nhận hình học và kết nối trong phạm vi antenna đã định nghĩa, không phải đo kiểm tầm xa ESP-NOW, hiệu suất RF, nhiễu khi motor chạy hoặc bảo đảm bay ổn định. JLCDFM phía dịch vụ chưa được chạy lại do trang tải trắng trong phiên trước. Các mục kiểm chứng phần cứng như dòng motor, nguồn và lựa chọn MPN L2 vẫn nằm trong báo cáo điện; không được coi là đã đo hoặc đã xác nhận chỉ vì DRC sạch.

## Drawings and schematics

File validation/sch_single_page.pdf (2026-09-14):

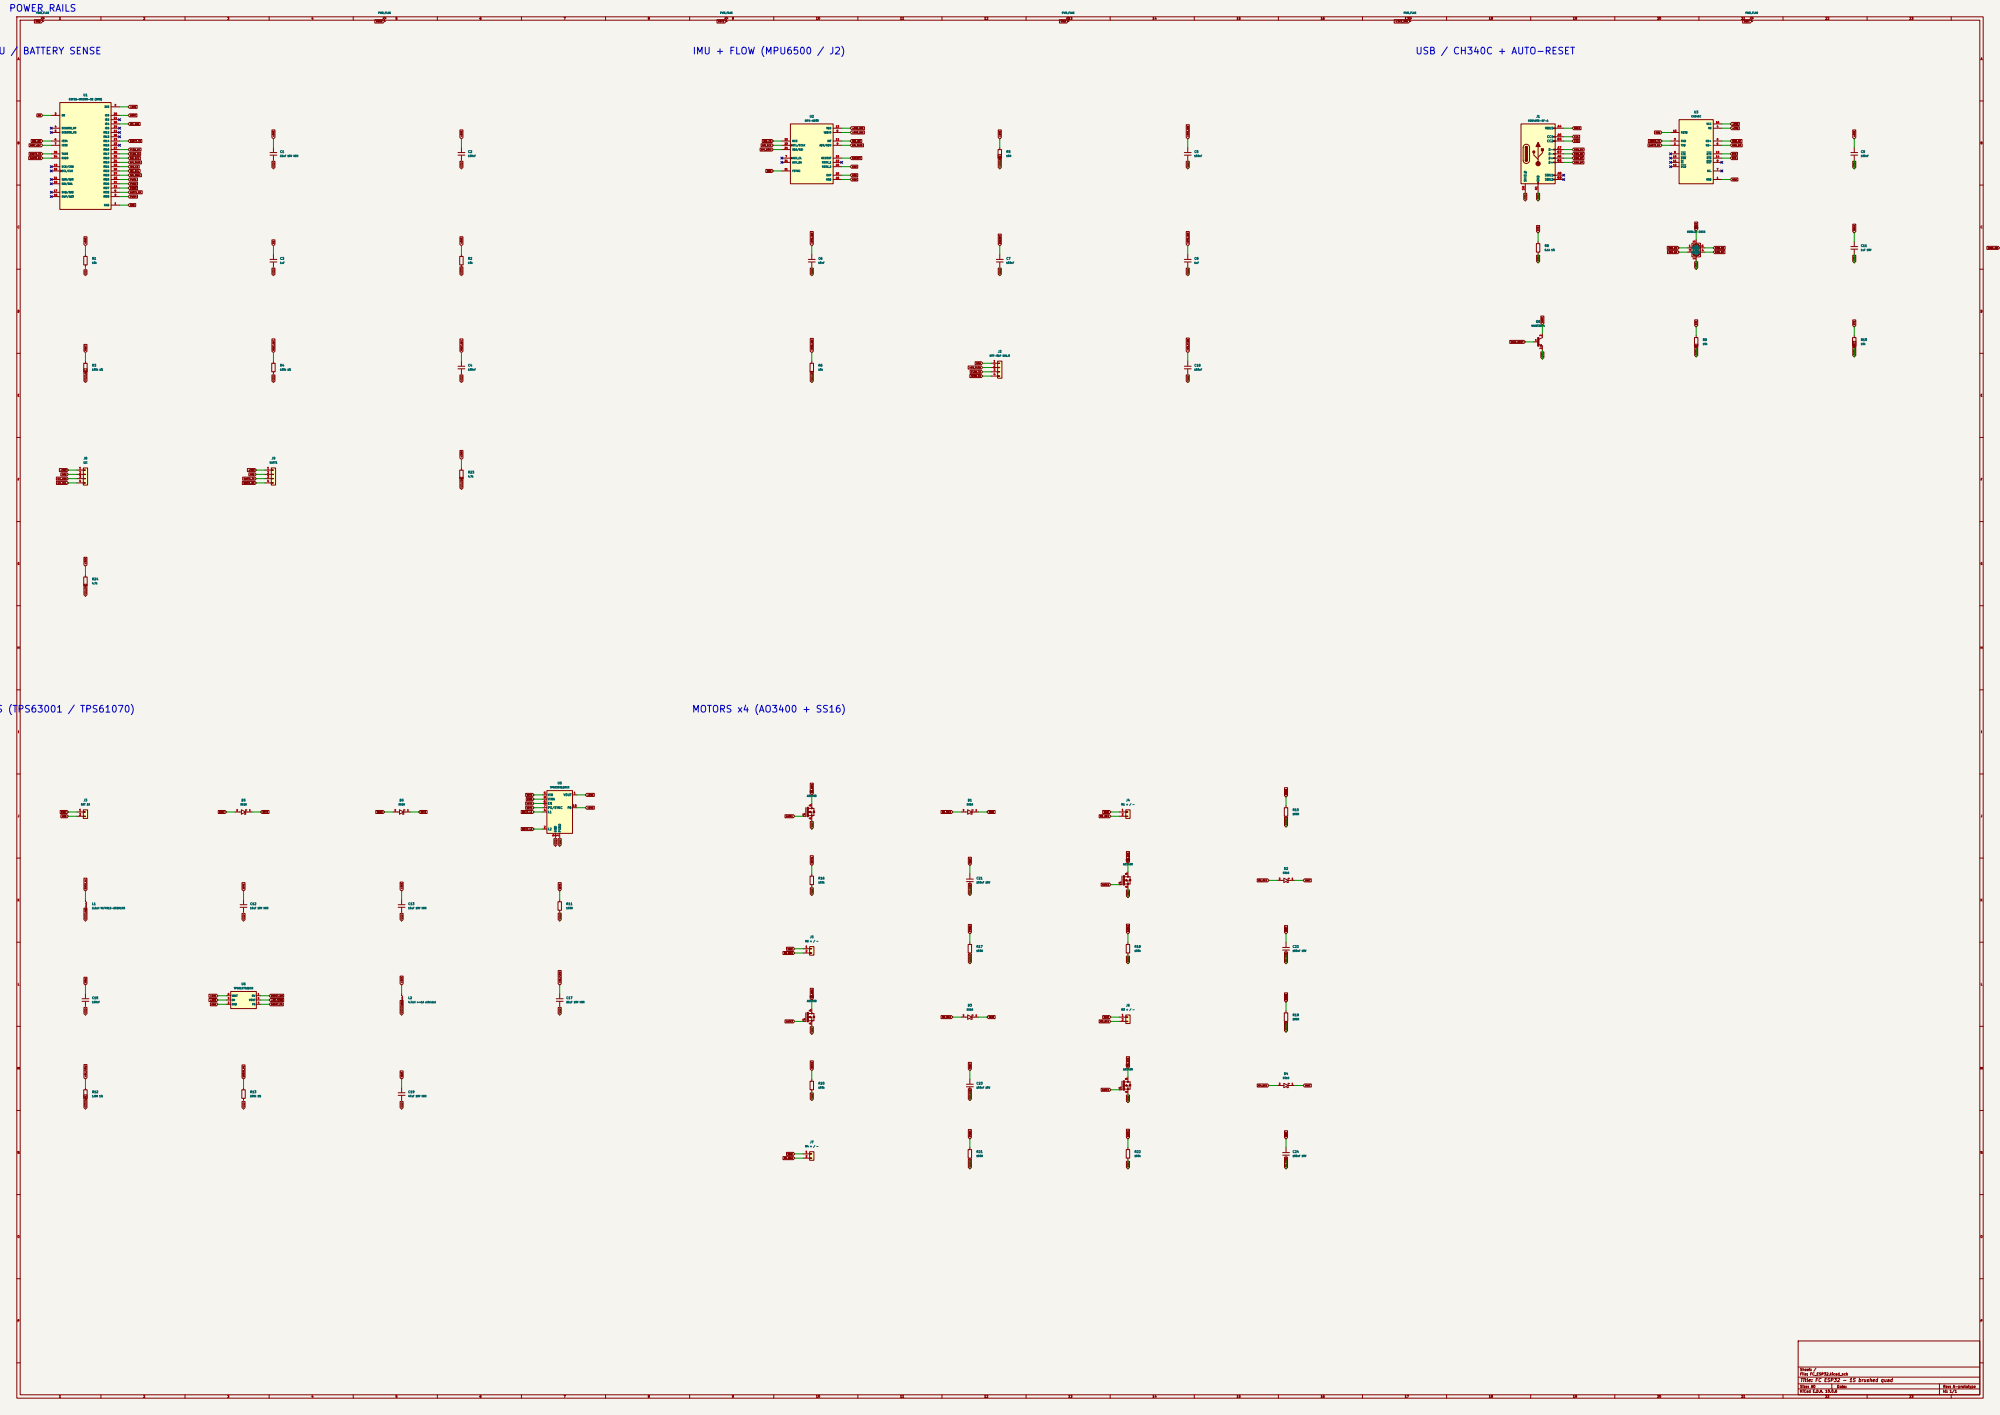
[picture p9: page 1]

Sheet: /
File: FC_ESP32.kicad_sch
Title: FC ESP32 - 1S brushed quad

Size: A0 | Rev: A-prototype
KiCad E.D.A. 10.0.6 | Id: 1/1

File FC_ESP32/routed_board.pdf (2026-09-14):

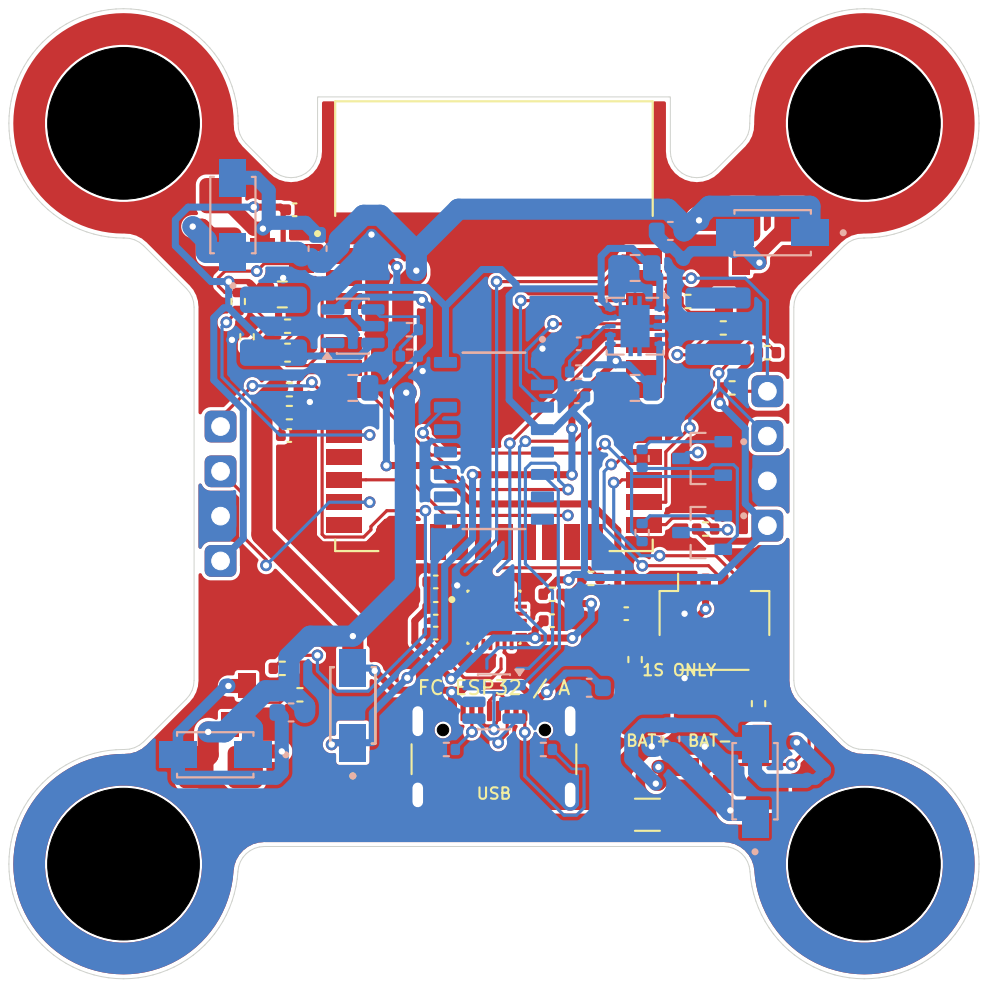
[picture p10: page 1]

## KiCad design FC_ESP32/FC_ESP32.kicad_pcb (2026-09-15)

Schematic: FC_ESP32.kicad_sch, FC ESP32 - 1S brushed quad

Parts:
C1, C17: 22uF 10V X5R; C_0805_2012Metric
C2, C4, C5, C7, C9, C15, C18: 100nF; C_0402_1005Metric
C3: 1uF; C_0603_1608Metric
C6: 10nF; C_0402_1005Metric
C8: 1uF; C_0402_1005Metric
C11: 1uF 10V; C_0603_1608Metric
C12, C13: 10uF 10V X5R; C_0805_2012Metric
C19: 47uF 10V X5R; C_1206_3216Metric
C21, C22, C23, C24: 100nF 10V; C_0603_1608Metric
D1, D2, D3, D4, D5, D6: SS16
J1: USB4105-GF-A; USB_C
J2: MTF-01P SH1.0; JST_SH_SM04B-SRSS-TB_1x04-1MP_P1.00mm_Horizontal
J3: BAT 1S; Battery_Wire_Pads
J4: M1 + / -; Motor_Wire_Pads
J5: M2 + / -; Motor_Wire_Pads
J6: M3 + / -; Motor_Wire_Pads
J7: M4 + / -; Motor_Wire_Pads
J8: I2C; Header_1x04_P2.54mm
J9: UART1; Header_1x04_P2.54mm
L1: 2.2uH VLF4012-2R2M1R5; L_VLF4012
L2: 4.7uH >=1A shielded; L_4x4
Q1, Q2, Q3, Q4: AO3400
Q5, Q6: MMBT3904
R1, R2, R6, R9, R10: 10k; R_0402_1005Metric
R3, R4: 100k 1%; R_0402_1005Metric
R5: 10R; R_0402_1005Metric
R7, R8: 5.1k 1%; R_0402_1005Metric
R11, R15, R17, R19, R21: 100R; R_0402_1005Metric
R12: 1.8M 1%; R_0402_1005Metric
R13: 200k 1%; R_0402_1005Metric
R16, R18, R20, R22: 100k; R_0402_1005Metric
R23, R24: 4.7k; R_0402_1005Metric
U1: ESP32-WROOM-32 (8MB); ESP32
U2: MPU-6500; MPU6500
U3: CH340C
U4: USBLC6-2SC6; SOT-23-6
U5: TPS63001DRCR; Texas_DRC0010J
U6: TPS61070DDCR; SOT-23-6

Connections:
+3V3: C1.1, C2.1, C9.1, C13.1, J8.1, J9.1, L2.1, R1.1, R2.1, R5.1, R23.1, R24.1, U1.2 (3V3), U3.4 (V3), U3.16 (VCC), U5.1 (VOUT), U5.10 (FB), U6.3 (EN), U6.6 (VBAT)
+3V3_IMU: C5.1, C6.1, C8.1, R5.2, R6.1, U2.8 (VDDIO), U2.13 (VDD)
+5V_FLOW: C17.1, C18.1, J2.2, R12.1, U6.5 (VOUT)
BASE_BOOT: Q6.1, R10.2
BASE_EN: Q5.1, R9.2
BOOST_FB: R12.2, R13.1, U6.4 (FB)
BOOST_SW: L2.2, U6.1 (SW)
BOOT: Q6.3, R2.2, U1.25 (IO0)
BUCK_L1: L1.1, U5.4 (L1)
BUCK_L2: L1.2, U5.2 (L2)
CC1: J1.A5 (CC1), R7.1
CC2: J1.B5 (CC2), R8.1
DTR: Q6.2, R9.1, U3.13 (~DTR)
EN: C3.1, Q5.3, R1.2, U1.3 (EN)
FLOW_RX: J2.4, U1.27 (IO16)
FLOW_TX: J2.3, U1.28 (IO17)
GATE1: Q1.1, R15.2, R16.1
GATE2: Q2.1, R17.2, R18.1
GATE3: Q3.1, R19.2, R20.1
GATE4: Q4.1, R21.2, R22.1
GND: C1.2, C2.2, C3.2, C4.2, C5.2, C6.2, C7.2, C8.2, C9.2, C11.2, C12.2, C13.2, C15.2, C17.2, C18.2, C19.2, J1.A1 (GND), J1.A12 (GND), J1.B1 (GND), J1.B12 (GND), J1.SH (SHIELD), J2.1, J3.2, J8.2, J9.2, Q1.2, Q2.2, Q3.2, Q4.2, R4.2, R7.2, R8.2, R13.2, R16.2, R18.2, R20.2, R22.2, U1.1 (GND), U1.15 (GND), U1.38 (GND), U1.39 (GND), U2.11 (FSYNC), U2.18 (GND), U2.20 (RESV_2), U2.25 (EXP), U3.1 (GND), U3.15 (R232), U4.2 (GND), U5.3 (PGND), U5.9 (GND), U5.11 (PGND), U6.2 (GND)
I2C_SCL: J8.4, R24.2, U1.36 (IO22)
I2C_SDA: J8.3, R23.2, U1.26 (IO4)
IMU_CS: R6.2, U1.33 (IO21), U2.22 (NCS)
IMU_INT: U1.6 (IO34), U2.12 (INT)
M1_NEG: C21.2, D1.2, J4.2, Q1.3
M2_NEG: C22.2, D2.2, J5.2, Q2.3
M3_NEG: C23.2, D3.2, J6.2, Q3.3
M4_NEG: C24.2, D4.2, J7.2, Q4.3
PWM1: R15.1, U1.10 (IO25)
PWM2: R17.1, U1.11 (IO26)
PWM3: R19.1, U1.12 (IO27)
PWM4: R21.1, U1.9 (IO33)
REGOUT: C7.1, U2.10 (REGOUT)
RTS: Q5.2, R10.1, U3.14 (~RTS)
SPI_MISO: U1.31 (IO19), U2.9 (AD0/SDO)
SPI_MOSI: U1.37 (IO23), U2.24 (SDA/SDI)
SPI_SCK: U1.30 (IO18), U2.23 (SCL/SCLK)
UART0_RX: U1.34 (RXD0), U3.2 (TXD)
UART0_TX: U1.35 (TXD0), U3.3 (RXD)
UART1_RX: J9.4, U1.8 (IO32)
UART1_TX: J9.3, U1.13 (IO14)
USB_DM: J1.A7 (D-), J1.B7 (D-), U3.6 (UD-), U4.1 (I/O1), U4.6 (I/O1)
USB_DP: J1.A6 (D+), J1.B6 (D+), U3.5 (UD+), U4.3 (I/O2), U4.4 (I/O2)
VBAT: C19.1, C21.1, C22.1, C23.1, C24.1, D1.1, D2.1, D3.1, D4.1, D5.2, J3.1, J4.1, J5.1, J6.1, J7.1, R3.1
VBAT_ADC: C4.1, R3.2, R4.1, U1.7 (IO35)
VBUS: C11.1, D6.2, J1.A4 (VBUS), J1.A9 (VBUS), J1.B4 (VBUS), J1.B9 (VBUS), U4.5 (VBUS)
VINA: C15.1, R11.2, U5.8 (VINA)
VSYS: C12.1, D5.1, D6.1, R11.1, U5.5 (VIN), U5.6 (EN), U5.7 (PS/SYNC)

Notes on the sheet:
POWER RAILS
MCU / BATTERY SENSE
IMU + FLOW (MPU6500 / J2)
USB / CH340C + AUTO-RESET
POWER 1S (TPS63001 / TPS61070)
MOTORS x4 (AO3400 + SS16)

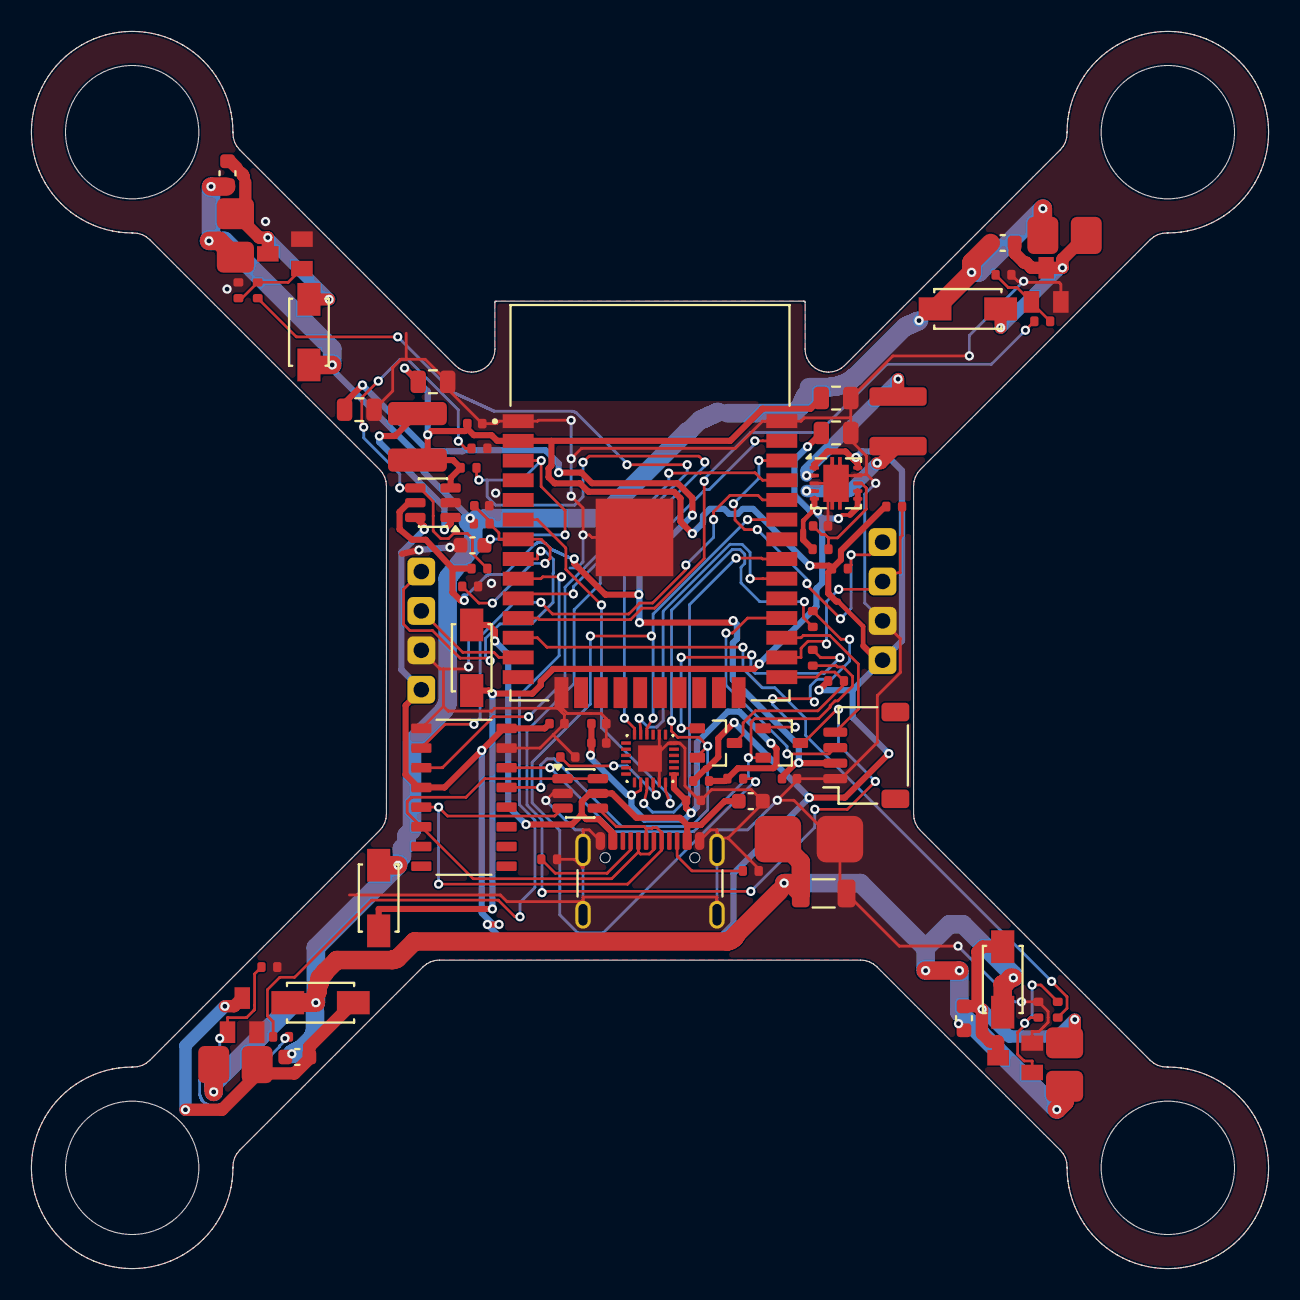
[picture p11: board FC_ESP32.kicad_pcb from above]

Board: 2 copper layers, 79.8 x 79.8 mm, 76 parts (0 on the bottom side), 49 nets.

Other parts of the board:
H1, H2, H3, H4: (no value)

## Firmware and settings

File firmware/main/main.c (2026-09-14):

#include <stdio.h>
#include "freertos/FreeRTOS.h"
#include "freertos/task.h"
#include "driver/ledc.h"
#include "driver/spi_master.h"
#include "driver/gpio.h"
#include "driver/uart.h"
#include "driver/i2c_master.h"
#include "esp_log.h"
#include "esp_adc/adc_oneshot.h"
#include "hal/adc_types.h"
#include "mpu6500.h"
#include "fc_radio.h"
#include "fc_control.h"
#include "esp_timer.h"
#include "esp_adc/adc_cali.h"
#include "esp_adc/adc_cali_scheme.h"
#include "sdkconfig.h"

static const char *TAG = "FC_MAIN";

// Motor PWM Pins
#define MOTOR1_PIN 25
#define MOTOR2_PIN 26
#define MOTOR3_PIN 27
#define MOTOR4_PIN 33

// MPU-6500 SPI Pins
#define MPU_MISO_PIN 19
#define MPU_MOSI_PIN 23
#define MPU_CLK_PIN  18
#define MPU_CS_PIN   21
#define MPU_INT_PIN  34
#define SPI_HOST    VSPI_HOST

// LEDC Configuration
#define LEDC_TIMER              LEDC_TIMER_0
#define LEDC_MODE               LEDC_LOW_SPEED_MODE
#define LEDC_DUTY_RES           LEDC_TIMER_13_BIT 
#define LEDC_FREQUENCY          400 

// Optical Flow (MTF-01P) UART2
#define OPTFLOW_UART_NUM UART_NUM_2
#define OPTFLOW_TX_PIN   GPIO_NUM_17
#define OPTFLOW_RX_PIN   GPIO_NUM_16
#define OPTFLOW_BUF_SIZE 256

// I2C Expansion
#define I2C_MASTER_SCL_IO           GPIO_NUM_22      
#define I2C_MASTER_SDA_IO           GPIO_NUM_4       
#define I2C_MASTER_NUM              I2C_NUM_0        
#define I2C_MASTER_FREQ_HZ          400000

// UART1 Expansion
#define EXP_UART_NUM UART_NUM_1
#define EXP_TX_PIN   GPIO_NUM_14
#define EXP_RX_PIN   GPIO_NUM_32

// Battery ADC
#define BATT_ADC_CHAN ADC_CHANNEL_7 // GPIO35
static adc_oneshot_unit_handle_t adc1_handle;
static adc_cali_handle_t adc_calibration;
i2c_master_bus_handle_t i2c_bus_handle;
static spi_device_handle_t spi_mpu;

static void init_motor_pwm(void) {
    ESP_LOGI(TAG, "Initializing Motor PWM...");
    ledc_timer_config_t ledc_timer = {
        .speed_mode       = LEDC_MODE,
        .timer_num        = LEDC_TIMER,
        .duty_resolution  = LEDC_DUTY_RES,
        .freq_hz          = LEDC_FREQUENCY,
        .clk_cfg          = LEDC_AUTO_CLK
    };
    ESP_ERROR_CHECK(ledc_timer_config(&ledc_timer));

    int motor_pins[4] = {MOTOR1_PIN, MOTOR2_PIN, MOTOR3_PIN, MOTOR4_PIN};
    for (int i = 0; i < 4; i++) {
        ledc_channel_config_t ledc_channel = {
            .speed_mode     = LEDC_MODE,
            .channel        = (ledc_channel_t)i,
            .timer_sel      = LEDC_TIMER,
            .intr_type      = LEDC_INTR_DISABLE,
            .gpio_num       = motor_pins[i],
            .duty           = 0,
            .hpoint         = 0
        };
        ESP_ERROR_CHECK(ledc_channel_config(&ledc_channel));
    }
}

static void init_mpu6500_spi(void) {
    ESP_LOGI(TAG, "Initializing MPU-6500 SPI...");
    spi_bus_config_t buscfg = {
        .miso_io_num = MPU_MISO_PIN,
        .mosi_io_num = MPU_MOSI_PIN,
        .sclk_io_num = MPU_CLK_PIN,
        .quadwp_io_num = -1,
        .quadhd_io_num = -1,
        .max_transfer_sz = 32
    };
    
    spi_device_interface_config_t devcfg = {
        .clock_speed_hz = 1000000,
        .mode = 3,
        .spics_io_num = MPU_CS_PIN,
        .queue_size = 7,
    };
    
    ESP_ERROR_CHECK(spi_bus_initialize(SPI_HOST, &buscfg, SPI_DMA_CH_AUTO));
    ESP_ERROR_CHECK(spi_bus_add_device(SPI_HOST, &devcfg, &spi_mpu));
    
    gpio_config_t int_conf = {
        .intr_type = GPIO_INTR_DISABLE,
        .pin_bit_mask = (1ULL << MPU_INT_PIN),
        .mode = GPIO_MODE_INPUT,
        .pull_up_en = GPIO_PULLUP_DISABLE,
        .pull_down_en = GPIO_PULLDOWN_DISABLE
    };
    ESP_ERROR_CHECK(gpio_config(&int_conf));
}

void battery_adc_init(void) {
    adc_oneshot_unit_init_cfg_t init_config = {
        .unit_id = ADC_UNIT_1,
    };
    ESP_ERROR_CHECK(adc_oneshot_new_unit(&init_config, &adc1_handle));

    adc_oneshot_chan_cfg_t config = {
        .bitwidth = ADC_BITWIDTH_DEFAULT,
        .atten = ADC_ATTEN_DB_12,
    };
    ESP_ERROR_CHECK(adc_oneshot_config_channel(adc1_handle, BATT_ADC_CHAN, &config));
    adc_cali_line_fitting_config_t cal = {
        .unit_id=ADC_UNIT_1, .atten=ADC_ATTEN_DB_12,
        .bitwidth=ADC_BITWIDTH_DEFAULT, .default_vref=1100,
    };
    ESP_ERROR_CHECK(adc_cali_create_scheme_line_fitting(&cal, &adc_calibration));
}

void optflow_uart_init(void) {
    uart_config_t uart_config = {
        .baud_rate = 115200,
        .data_bits = UART_DATA_8_BITS,
        .parity    = UART_PARITY_DISABLE,
        .stop_bits = UART_STOP_BITS_1,
        .flow_ctrl = UART_HW_FLOWCTRL_DISABLE,
        .source_clk = UART_SCLK_DEFAULT,
    };
    ESP_ERROR_CHECK(uart_param_config(OPTFLOW_UART_NUM, &uart_config));
    ESP_ERROR_CHECK(uart_set_pin(OPTFLOW_UART_NUM, OPTFLOW_TX_PIN, OPTFLOW_RX_PIN, UART_PIN_NO_CHANGE, UART_PIN_NO_CHANGE));
    ESP_ERROR_CHECK(uart_driver_install(OPTFLOW_UART_NUM, OPTFLOW_BUF_SIZE * 2, 0, 0, NULL, 0));
}

void exp_uart_init(void) {
    uart_config_t uart_config = {
        .baud_rate = 115200,
        .data_bits = UART_DATA_8_BITS,
        .parity    = UART_PARITY_DISABLE,
        .stop_bits = UART_STOP_BITS_1,
        .flow_ctrl = UART_HW_FLOWCTRL_DISABLE,
        .source_clk = UART_SCLK_DEFAULT,
    };
    ESP_ERROR_CHECK(uart_param_config(EXP_UART_NUM, &uart_config));
    ESP_ERROR_CHECK(uart_set_pin(EXP_UART_NUM, EXP_TX_PIN, EXP_RX_PIN, UART_PIN_NO_CHANGE, UART_PIN_NO_CHANGE));
    ESP_ERROR_CHECK(uart_driver_install(EXP_UART_NUM, 256 * 2, 0, 0, NULL, 0));
}

void i2c_master_init(void) {
    i2c_master_bus_config_t i2c_bus_config = {
        .clk_source = I2C_CLK_SRC_DEFAULT,
        .i2c_port = I2C_MASTER_NUM,
        .scl_io_num = I2C_MASTER_SCL_IO,
        .sda_io_num = I2C_MASTER_SDA_IO,
        .glitch_ignore_cnt = 7,
        .flags.enable_internal_pullup = true,
    };
    ESP_ERROR_CHECK(i2c_new_master_bus(&i2c_bus_config, &i2c_bus_handle));
}

static bool write_motors(const float duty[4]) {
    for (int i=0;i<4;i++) {
#ifdef CONFIG_FC_ENABLE_MOTORS
        uint32_t value=(uint32_t)(duty[i]*8191.0f);
#else
        (void)duty;
        uint32_t value=0;
#endif
        if (ledc_set_duty(LEDC_MODE,(ledc_channel_t)i,value)!=ESP_OK ||
            ledc_update_duty(LEDC_MODE,(ledc_channel_t)i)!=ESP_OK) {
            for (int j=0;j<4;j++)ledc_stop(LEDC_MODE,(ledc_channel_t)j,0);
            return false;
        }
    }
    return true;
}

static void sensor_task(void *pvParameters) {
    (void)pvParameters;
    fc_control_t controller;
    fc_control_init(&controller);
    TickType_t wake=xTaskGetTickCount();
    const TickType_t period=pdMS_TO_TICKS(2);
    configASSERT(period>0);
    int64_t last=esp_timer_get_time(),last_adc=0,last_log=0;
    float battery=0;
    bool battery_ok=false;
    while (1) {
        int64_t now=esp_timer_get_time();
        float dt=(now-last)*1e-6f;
        last=now;
        fc_command_t command;
        bool link_armed=fc_radio_snapshot(&command);
        fc_imu_t sample;
        esp_err_t imu_error=mpu6500_read_sample(&sample);
        if (now-last_adc>=20000) {
            int raw,mv;
            battery_ok=adc_oneshot_read(adc1_handle,BATT_ADC_CHAN,&raw)==ESP_OK &&
                adc_cali_raw_to_voltage(adc_calibration,raw,&mv)==ESP_OK;
            if (battery_ok)battery=mv*.002f; // 100k/100k divider
            battery_ok=battery_ok && battery>=3.5f && battery<=4.45f;
            last_adc=now;
        }
        float motors[4]={0};
        if (imu_error!=ESP_OK || !battery_ok) {
            // Fault recovery requires calibration and a new disarm/arm sequence.
            fc_control_init(&controller);
        } else {
            fc_control_step(&controller,&sample,&command,link_armed,dt,motors);
        }
        if (!write_motors(motors))fc_control_init(&controller);
        if (now-last_log>=1000000) {
            ESP_LOGI(TAG,"battery=%.2f V ready=%d armed=%d roll=%.1f pitch=%.1f",
                battery,controller.ready,controller.armed,controller.roll,controller.pitch);
            last_log=now;
        }
        vTaskDelayUntil(&wake,period);
    }
}

void app_main(void) {
    ESP_LOGI(TAG, "Starting FC_ESP32 Flight Controller...");
#ifndef CONFIG_FC_ENABLE_MOTORS
    ESP_LOGW(TAG,"Motor outputs inhibited by build configuration");
#endif
    init_motor_pwm();
    init_mpu6500_spi();
    ESP_ERROR_CHECK(mpu6500_init(spi_mpu));
    battery_adc_init();
    optflow_uart_init();
    exp_uart_init();
    i2c_master_init();
    esp_err_t radio_error = fc_radio_init();
    if (radio_error != ESP_OK)
        ESP_LOGW(TAG, "ESP-NOW unavailable: %s; configure peer MAC and keys", esp_err_to_name(radio_error));
    
    if (xTaskCreate(sensor_task, "sensor_task", 4096, NULL, 5, NULL) != pdPASS) {
        ESP_LOGE(TAG, "Could not create sensor task; motors remain stopped");
    }
}

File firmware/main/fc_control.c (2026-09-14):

#include "fc_control.h"
#include <math.h>
#include <string.h>
#define DEG 57.2957795131f
#define CALIBRATION_SAMPLES 500
static float limit(float x,float low,float high) { return fminf(high,fmaxf(low,x)); }
void fc_control_init(fc_control_t *s) {
    memset(s,0,sizeof(*s));
    // Provisional normalized-output gains. Bench tuning is mandatory.
    pid_init(&s->roll_pid,.0012f,.0004f,.00001f,100,.25f);
    pid_init(&s->pitch_pid,.0012f,.0004f,.00001f,100,.25f);
    pid_init(&s->yaw_pid,.0015f,.0004f,0,100,.25f);
}
static void stop(fc_control_t *s) {
    s->armed=false; s->arm_allowed=false;
    pid_reset(&s->roll_pid);pid_reset(&s->pitch_pid);pid_reset(&s->yaw_pid);
}
bool fc_control_step(fc_control_t *s,const fc_imu_t *v,const fc_command_t *c,
                     bool link_armed,float dt,float motors[4]) {
    memset(motors,0,4*sizeof(float));
    if (!isfinite(v->ax)||!isfinite(v->ay)||!isfinite(v->az)||!isfinite(v->gx)||
        !isfinite(v->gy)||!isfinite(v->gz)||!isfinite(dt)||dt<.0005f||dt>.01f) {
        stop(s); return false;
    }
    float magnitude=sqrtf(v->ax*v->ax+v->ay*v->ay+v->az*v->az);
    float accel_roll=atan2f(v->ay,v->az)*DEG;
    float accel_pitch=atan2f(-v->ax,hypotf(v->ay,v->az))*DEG;
    if (!s->ready) {
        stop(s);
        if (magnitude<.9f||magnitude>1.1f||fabsf(v->gx)>5||fabsf(v->gy)>5||
            fabsf(v->gz)>5||fabsf(accel_roll)>10||fabsf(accel_pitch)>10) {
            s->calibration_samples=0;memset(s->bias,0,sizeof(s->bias));return false;
        }
        s->bias[0]+=v->gx;s->bias[1]+=v->gy;s->bias[2]+=v->gz;
        if (++s->calibration_samples==CALIBRATION_SAMPLES) {
            for (int i=0;i<3;i++)s->bias[i]/=CALIBRATION_SAMPLES;
            s->roll=accel_roll;s->pitch=accel_pitch;s->ready=true;
        }
        return false;
    }
    float gx=v->gx-s->bias[0],gy=v->gy-s->bias[1],gz=v->gz-s->bias[2];
    // Complementary filter, 0.5 s accelerometer correction time constant.
    float alpha=.5f/(.5f+dt);
    s->roll+=gx*dt;s->pitch+=gy*dt;
    if (magnitude>.8f && magnitude<1.2f) {
        s->roll=alpha*s->roll+(1-alpha)*accel_roll;
        s->pitch=alpha*s->pitch+(1-alpha)*accel_pitch;
    }
    if (fabsf(s->roll)>60 || fabsf(s->pitch)>60) {stop(s);return false;}
    if (!link_armed) {stop(s);s->arm_allowed=c->throttle==0;return false;}
    if (!s->armed) {
        s->armed=s->arm_allowed && c->throttle==0;s->arm_allowed=false;
        if (!s->armed)return false;
    }
    if (c->throttle==0) {
        pid_reset(&s->roll_pid);pid_reset(&s->pitch_pid);pid_reset(&s->yaw_pid);
        return true;
    }
    float roll_rate=limit((c->roll*.020f-s->roll)*4,-150,150);
    float pitch_rate=limit((c->pitch*.020f-s->pitch)*4,-150,150);
    float roll=pid_update(&s->roll_pid,roll_rate,gx,dt);
    float pitch=pid_update(&s->pitch_pid,pitch_rate,gy,dt);
    float yaw=pid_update(&s->yaw_pid,c->yaw*.12f,gz,dt);
    float throttle=c->throttle*.001f;
    // NW, NE, SE, SW. Signs/rotation direction need a restrained bench check.
    motors[0]=limit(throttle-pitch+roll+yaw,0,1);
    motors[1]=limit(throttle-pitch-roll-yaw,0,1);
    motors[2]=limit(throttle+pitch-roll+yaw,0,1);
    motors[3]=limit(throttle+pitch+roll-yaw,0,1);
    return true;
}
